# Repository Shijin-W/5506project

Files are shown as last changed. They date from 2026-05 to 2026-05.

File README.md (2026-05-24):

# Smart Multi-Cat Feeder

An IoT-based automatic cat feeder that identifies individual cats via RFID, serves food from dedicated bowls, measures food intake, and reports data to the cloud for remote monitoring.

## Table of Contents

- [Project Overview](#project-overview)
- [System Architecture](#system-architecture)
- [Hardware Setup](#hardware-setup)
- [Software Installation](#software-installation)
- [How It Works](#how-it-works)
- [Project Structure](#project-structure)
- [Code Overview](#code-overview)

## Project Overview

Multi-cat households face a common problem: one cat may eat another's food, leading to over-feeding or under-feeding. This project solves it by:

1. **RFID Identification** — Each cat wears an RFID tag on its collar. The feeder reads the tag and rotates a turntable to present the correct food bowl.
2. **Weight Measurement** — Load cells under each bowl measure food intake per session.
3. **Cloud Monitoring** — Feeding records are sent to Azure IoT Hub, processed by Azure Functions, and displayed on a web dashboard.
4. **Health Alerts** — If a cat hasn't eaten or exceeds its daily target, the system sends email alerts to the owner.

## Hardware Setup

### Components Required

| Component | Model | Qty | Interface |
|---|---|-----|---|
| Microcontroller | DFRobot FireBeetle 2 ESP32-E | 1 | — |
| RFID Reader | MFRC522 (I2C version) | 1 | I2C (0x2C) |
| Distance Sensor | VL53L1X Time-of-Flight | 1 | I2C (0x29) |
| Stepper Motor | 28BYJ-48 + ULN2003 driver | 1 | GPIO |
| Load Cell + Amplifier | HX711 | 2 | GPIO |
| RFID Tags | 13.56 MHz passive tags | 1 per cat | — |
| Power Supply | 5 V USB | 1 | — |

### Wiring Diagram

**I2C Bus** (shared by RFID reader and distance sensor):

| ESP32 Pin | Function |
|---|---|
| GPIO 21 | SDA |
| GPIO 22 | SCL |

**Stepper Motor** (28BYJ-48 via ULN2003 driver):

| ESP32 Pin | ULN2003 |
|---|---|
| GPIO 25 | IN1 |
| GPIO 26 | IN2 |
| GPIO 14 | IN3 |
| GPIO 13 | IN4 |

**Load Cells** (HX711 amplifiers):

| ESP32 Pin | Function |
|---|---|
| GPIO 17 | Left bowl HX711 DOUT  |
| GPIO 16 | Left bowl HX711 SCK |
| GPIO 18 | Right bowl HX711 DOUT |
| GPIO 19 | Right bowl HX711 SCK  |

### Physical Assembly

1. Mount the RFID reader at the bottom of the feeding tunnel, below the feeding window.
2. Mount the VL53L1X sensor on the tunnel side wall, facing the opposite wall.
3. Fix the stepper motor below the 3D-printed turntable (STL files in `hardware/3d/`).
4. Place two food bowls on the turntable, each sitting on a load cell.
5. Place the ESP32 and breadboard inside the housing box underneath the turntable.

## Software Installation

### Prerequisites

| Tool | Purpose |
|---|---|
| [PlatformIO](https://platformio.org/) | Build and upload ESP32 firmware |
| [Python 3.9+](https://www.python.org/) | Run the backend (Azure Functions) |
| [Azure CLI](https://learn.microsoft.com/en-us/cli/azure/) | Deploy backend to Azure (optional) |
| [Azure Functions Core Tools](https://learn.microsoft.com/en-us/azure/azure-functions/functions-run-local) | Run backend locally (optional) |

### 1. ESP32 Firmware

```bash
cd hardware/code
```

**Configure credentials** — edit `include/azure_config.h`:

```cpp
#define WIFI_SSID       "YourWiFiName"
#define WIFI_PASSWORD   "YourWiFiPassword"
#define IOT_HUB_HOST    "your-hub.azure-devices.net"
#define DEVICE_ID       "your-device-id"
#define DEVICE_KEY      "your-device-primary-key"
```

**Build and upload:**

```bash
pio run                          # Build firmware
pio run --target upload          # Flash to ESP32
pio device monitor --baud 115200 # View serial output
```

All library dependencies are listed in `platformio.ini` and will be downloaded automatically on the first build.

### 2. Azure Functions Backend

```bash
cd backend
pip install -r requirements.txt
```

**Configure environment** — copy the template and fill in your Azure credentials:

```bash
cp local.settings.template.json local.settings.json
# Edit local.settings.json with your Azure connection strings
```

Required settings: `AzureWebJobsStorage`, `STORAGE_CONNECTION_STRING`, `IOT_HUB_EVENTHUB_CONNECTION`, `IOT_HUB_EVENTHUB_NAME`, `IOT_HUB_CONNECTION_STRING`, `IOT_HUB_DEVICE_ID`, `LOCAL_TIMEZONE`.

**Seed initial cat profiles:**

```bash
python tools/seed_cat_profiles.py
```

**Deploy to Azure:**

```bash
func azure functionapp publish <function-app-name>
```

### 3. Web Dashboard (Frontend)

The frontend is a static website — no build step required.

```bash
cd frontend
python -m http.server 8088 --bind 127.0.0.1
```

Open `http://127.0.0.1:8088/index.html` in a browser.

To connect to a live backend, create `static/js/config.local.js`:

```javascript
window.FEEDER_CONFIG = {
  BACKEND_BASE_URL: "https://<function-app-name>.azurewebsites.net",
  FUNCTION_KEY: "<your-function-key>"
};
```

Load this file before `api.js` in the HTML pages.

## How It Works

### Firmware State Machine

The ESP32 firmware runs a **6-state finite state machine (FSM)** in a non-blocking `loop()`:

```
IDLE ──► DETECTING ──► OPENING ──► FEEDING ──► CLOSING ──► IDLE
                                                    
IDLE ──► SCAN_RFID ──► IDLE       (Cloud-triggered RFID binding)
```

| State | Description |
|---|---|
| **IDLE** | Distance sensor monitors the tunnel entrance. Transitions to DETECTING when an object is detected within 50 mm. |
| **DETECTING** | RFID reader attempts to identify the cat (5-second timeout). On match, motor begins rotating to the assigned bowl. |
| **OPENING** | Waits for the stepper motor to reach the target position. Records initial food weight from the load cell. |
| **FEEDING** | Cat is eating. Monitors for departure (3 seconds of continuous absence) and enforces a 5-minute max feeding time. |
| **CLOSING** | Motor returns to home position with backlash compensation. Feeding record (duration, intake) is uploaded to Azure IoT Hub. |
| **SCAN_RFID** | Triggered by a Cloud-to-Device command for remote RFID tag rebinding. Only available when IDLE. |

### Fault Tolerance

- **Sensor failure** — Any sensor that fails during boot is marked as unavailable. The system continues in degraded mode without freezing.
- **Network offline** — Feeding records are cached in a ring buffer (up to 10 records) and automatically resent when the connection is restored.
- **Token refresh** — SAS tokens are regenerated 2 minutes before expiry without interrupting the feeding process.

### Backend Processing

1. IoT Hub forwards device telemetry to Azure Functions via an Event Hub trigger.
2. The backend validates incoming events, maps RFID UIDs to cat profiles, and stores feeding records in Azure Table Storage.
3. Daily summaries and health alerts are computed automatically. If a cat hasn't eaten or exceeds its target, an alert is generated and optionally sent via email.
4. Pre-computed JSON files are written to Azure Blob Storage for fast frontend loading.

### Web Dashboard

| Page | Purpose |
|---|---|
| **Dashboard** (`index.html`) | Today's feeding count, total intake, active alerts, device status |
| **Feeding Records** (`records.html`) | Detailed feeding history with date filtering |
| **Analytics** (`analytics.html`) | Intake trends and charts over a date range |
| **Health Alerts** (`alerts.html`) | Alert history, manual resolution, email subscription |
| **Cat Management** (`cats.html`) | Edit cat profiles, set daily targets, rebind RFID tags |

## Project Structure

```
5506project/
├── hardware/
│   ├── code/
│   │   ├── include/
│   │   │   ├── config.h              # Pin assignments, thresholds, motor parameters
│   │   │   └── azure_config.h        # WiFi and Azure IoT Hub credentials
│   │   ├── src/
│   │   │   ├── main.cpp              # FSM logic and main loop
│   │   │   ├── rfid_module.cpp/h     # RFID reading, whitelist, NVS persistence
│   │   │   ├── motor_module.cpp/h    # Stepper motor with backlash compensation
│   │   │   ├── distance_module.cpp/h # VL53L1X cat presence detection
│   │   │   ├── loadcell_module.cpp/h # HX711 food weight measurement
│   │   │   └── azure_iot_module.cpp/h# MQTT, SAS auth, Device Twin, telemetry
│   │   └── platformio.ini            # Build config and library dependencies
│   ├── 3d/                           # 3D-printed enclosure STL files
│   └── images/                       # Hardware photos
│
├── backend/
│   ├── backend_app.py                # Azure Functions entry point (all HTTP + Event triggers)
│   ├── shared/
│   │   ├── status_service.py         # Core processing: feeding events, heartbeats, alerts
│   │   ├── table_repository.py       # Azure Table Storage data access layer
│   │   ├── blob_repository.py        # Azure Blob Storage data access layer
│   │   ├── twin_service.py           # Azure IoT Hub Device Twin and C2D messaging
│   │   ├── email_service.py          # Alert email notification (ACS / SMTP)
│   │   ├── alert_service.py          # Alert creation helpers
│   │   ├── config.py                 # App configuration from environment variables
│   │   ├── parser.py                 # IoT Hub message parser
│   │   ├── validator.py              # Feeding event payload validator
│   │   └── time_utils.py             # UTC/local time conversion utilities
│   ├── tests/                        # Unit tests (pytest)
│   └── tools/                        # Seed scripts, backfill, RFID update CLI
│
├── frontend/
│   ├── index.html                    # Dashboard page
│   ├── records.html                  # Feeding records page
│   ├── analytics.html                # Analytics page
│   ├── alerts.html                   # Health alerts page
│   ├── cats.html                     # Cat management page
│   └── static/
│       ├── css/style.css             # Global stylesheet
│       └── js/
│           ├── api.js                # Backend API client and data transformations
│           ├── dashboard.js          # Dashboard page logic
│           ├── records.js            # Records page logic
│           ├── analytics.js          # Analytics page logic (Chart.js)
│           ├── alerts.js             # Alerts page logic
│           └── cats.js               # Cat management page logic
│
└── README.md                         # This file
```

## Code Overview

### Hardware Modules

| Module | File(s) | Description |
|---|---|---|
| **Main FSM** | `main.cpp` | Implements the 6-state finite state machine. Calls sensor modules and Azure module each loop iteration. |
| **RFID** | `rfid_module.cpp/h` | Reads MFRC522 RFID tags over I2C. Manages a cat whitelist stored in ESP32 NVS (non-volatile storage). Supports mock tag injection for serial-based testing. |
| **Motor** | `motor_module.cpp/h` | Controls the 28BYJ-48 stepper motor via AccelStepper library. Implements a two-phase homing process: overshoot past home then return, to compensate for gear backlash. |
| **Distance** | `distance_module.cpp/h` | Reads VL53L1X Time-of-Flight sensor over I2C. Returns whether an object (cat) is within the threshold range. Runs in degraded mode if sensor init fails. |
| **Load Cell** | `loadcell_module.cpp/h` | Reads two HX711 load cell amplifiers. Averages 5 readings for stability. Note: negative readings after reboot are intentional — intake = initial − final weight. |
| **Azure IoT** | `azure_iot_module.cpp/h` | Manages WiFi, NTP, TLS, and MQTT connection to Azure IoT Hub. Generates SAS tokens using HMAC-SHA256. Handles Device Twin sync and Cloud-to-Device commands. Caches up to 10 unsent records for offline resilience. |

### Backend Functions

| Function | Trigger | Description |
|---|---|---|
| `process_iothub_feeding_event` | Event Hub | Processes raw IoT messages: validates, stores feeding events, recalculates daily summaries, and generates alerts. |
| `check_daily_feeding_status` | Timer (scheduled) | Ensures every cat has a daily status entry. Generates "not eaten" alerts for cats with no feedings. |
| `get_current_status` | HTTP GET | Returns current feeding status for all cats. |
| `get_daily_summary` | HTTP GET | Returns daily summary for a given date. |
| `get_recent_feedings` | HTTP GET | Returns feeding records for a given date. |
| `get_analytics_range` | HTTP GET | Returns aggregated analytics over a date range. |
| `get_alerts` / `get_alert_history` | HTTP GET | Returns alerts for a date or date range. |
| `resolve_alert` | HTTP POST | Manually resolves an open alert. |
| `alert_subscriptions` | HTTP GET/POST | Manage email alert subscriptions. |
| `update_cat_profile` | HTTP PATCH | Update cat name or daily target, pushes Device Twin. |
| `start_rfid_rebind_scan` | HTTP POST | Sends a Cloud-to-Device command to the ESP32 to scan a new RFID tag. |
| `sync_device_twin_config` | HTTP POST | Force-pushes the latest cat config to the Device Twin. |

### Frontend Pages

| Page | Key Features |
|---|---|
| **Dashboard** | Summary cards (feedings, intake, alerts, device status), today's intake by cat, latest feeding records, recent alerts. |
| **Feeding Records** | Full feeding history with date-range picker, per-record details (time, duration, intake). |
| **Analytics** | Chart.js line and bar charts for intake trends over custom date ranges. Per-cat summaries with averages. |
| **Health Alerts** | Alert history with severity levels, manual resolve action, email subscription management. |
| **Cat Management** | Edit cat names and daily targets, trigger RFID rebind scan workflow from the browser. |

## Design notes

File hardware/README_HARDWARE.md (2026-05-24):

# Smart Cat Feeder — Firmware (ESP32)

This directory contains the firmware for the Smart Cat Feeder, running on a DFRobot FireBeetle 2 ESP32-E. The system identifies cats via RFID, rotates a turntable to present the correct food bowl, measures food intake with load cells, and reports all data to Azure IoT Hub.

## Hardware Setup

### Components Required

| Component | Model | Quantity | Interface |
| --- | --- | --- | --- |
| Microcontroller | DFRobot FireBeetle 2 ESP32-E | 1 | — |
| RFID Reader | MFRC522 (Piico I2C version)  | 1 | I2C (addr 0x2C) |
| Distance Sensor | VL53L1X Time-of-Flight | 1 | I2C (addr 0x29) |
| Stepper Motor | 28BYJ-48 + ULN2003 driver | 1 | GPIO |
| Load Cell + Amplifier | HX711 | 2 | GPIO |
| RFID Tags | 13.56 MHz passive tags | per cat  | — |
| Power Supply | 5V USB | 1 | — |

### Wiring

**I2C Bus (shared by RFID and ToF):**

| ESP32 Pin | Function |
| --- | --- |
| GPIO 21 | SDA |
| GPIO 22 | SCL |

**Stepper Motor (28BYJ-48 via ULN2003):**

| ESP32 Pin | ULN2003 Pin |
| --- | --- |
| GPIO 25 | IN1 |
| GPIO 26 | IN2 |
| GPIO 14 | IN3 |
| GPIO 13 | IN4 |

**Load Cells (HX711):**

| ESP32 Pin | Function |
| --- | --- |
| GPIO 17 | Left bowl HX711 DOUT  |
| GPIO 16 | Left bowl HX711 SCK |
| GPIO 18 | Right bowl HX711 DOUT |
| GPIO 19 | Right bowl HX711 SCK  |

### Physical Assembly

1. Mount the RFID reader at the bottom of the feeding tunnel, just below the feeding window.
2. Mount the VL53L1X sensor on the side wall at the tunnel entrance, facing the opposite wall.
3. Fix the 28BYJ-48 motor below the 3D-printed turntable, with its shaft inserted into the centre.
4. Place two food bowls on the turntable, each on top of a load cell.
5. Place the ESP32 and breadboard inside the housing box underneath the turntable.

## Software Installation

### Prerequisites

- [PlatformIO](https://platformio.org/) (VS Code extension or CLI)
- USB cable for ESP32 flashing

### Configuration

1. Open `include/azure_config.h` and set your WiFi credentials and Azure IoT Hub device credentials:

```cpp
#define WIFI_SSID       "YourWiFiName"
#define WIFI_PASSWORD   "YourWiFiPassword"
#define IOT_HUB_HOST    "your-hub.azure-devices.net"
#define DEVICE_ID       "your-device-id"
#define DEVICE_KEY      "your-device-primary-key"
```

2. (Optional) Adjust sensor thresholds and motor parameters in `include/config.h` if your hardware setup differs from the default.

### Build and Upload

```bash
# Build the firmware
pio run

# Upload to the connected ESP32
pio run --target upload

# Open serial monitor to view logs
pio device monitor --baud 115200
```

All library dependencies (MFRC522_I2C, AccelStepper, HX711, VL53L1X, PubSubClient, ArduinoJson) are listed in `platformio.ini` and will be downloaded automatically on the first build.

## Project Structure

```
IOTProject/
├── include/
│   ├── config.h              # Pin assignments, thresholds, and motor parameters
│   └── azure_config.h        # WiFi and Azure IoT Hub credentials
├── src/
│   ├── main.cpp              # FSM logic and main loop
│   ├── rfid_module.cpp/h     # RFID reading, whitelist management, NVS persistence
│   ├── motor_module.cpp/h    # Stepper motor control with backlash compensation
│   ├── distance_module.cpp/h # VL53L1X distance sensor (cat presence detection)
│   ├── loadcell_module.cpp/h # HX711 load cell (food weight measurement)
│   └── azure_iot_module.cpp/h# Azure IoT Hub: MQTT, SAS auth, Device Twin, C2D, telemetry
└── platformio.ini            # Build configuration and library dependencies
```

## How It Works

The firmware runs a 6-state finite state machine (FSM) in a non-blocking main loop:

1. **IDLE** — Distance sensor monitors the tunnel entrance. When an object is detected, the system transitions to DETECTING.
2. **DETECTING** — RFID reader attempts to identify the cat. On success, the motor begins rotating to the assigned bowl position (OPENING). On timeout or cat departure, returns to IDLE.
3. **OPENING** — Waits for the stepper motor to reach the target bowl position. Records initial food weight from the load cell.
4. **FEEDING** — Cat is eating. The system monitors the distance sensor for cat departure (3-second absence confirmation) and enforces a 5-minute maximum feeding time.
5. **CLOSING** — Motor returns to home position with backlash compensation (overshoot + correction). Feeding record is uploaded to Azure IoT Hub.
6. **SCAN_RFID** — Triggered by a Cloud-to-Device command for remote RFID tag binding. Only available when IDLE.

### Fault Tolerance

- Any sensor failure at boot does not freeze the system; the module is marked as unavailable and the system runs in degraded mode.
- Feeding records are cached in a ring buffer (max 10) when the network is offline and automatically resent on reconnection.
- SAS tokens are auto-refreshed 2 minutes before expiry without interrupting the feeding process.

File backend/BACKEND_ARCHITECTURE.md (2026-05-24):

# Multicat Feeder Backend Architecture

本文档整理当前 `multicatfeeder` 项目的后端框架、Azure Functions 入口、数据存储设计、IoT 消息处理流程、告警逻辑、Device Twin 同步、邮件通知和前端数据接口。

## 1. Overall Architecture

后端是 Azure Functions Python 项目，使用经典 `function.json` 目录结构，而不是 Python v2 decorator 模式。

每个 Function 文件夹包含：

- `function.json`: Azure Functions binding 配置
- `__init__.py`: Function 入口，通常只转发到 `backend_app.py`

真实业务逻辑集中在：

- `backend_app.py`
- `shared/status_service.py`
- `shared/table_repository.py`
- `shared/blob_repository.py`
- `shared/parser.py`
- `shared/validator.py`
- `shared/alert_service.py`
- `shared/email_service.py`
- `shared/twin_service.py`
- `shared/time_utils.py`

当前后端使用：

- Azure Functions
- Azure IoT Hub Event Hub compatible endpoint
- Azure Table Storage
- Azure Blob Storage
- Azure IoT Hub Device Twin
- Azure IoT Hub Cloud-to-Device messages
- Azure Communication Email or SMTP, optional

## 2. Deployed Azure Resources

当前部署资源：

| Resource | Value |
|---|---|
| Resource group | `IOT-Group17` |
| Function App | `multicatfeeder-func-24417624` |
| IoT Hub | `multicatfeeder` |
| IoT Hub device | `feeder-esp32-01` |
| Project data storage account | `multicatproject` |
| Function runtime storage account | `mcfbackend24417624` |

项目数据和 Function runtime storage 是分开的。Table、Blob、前端静态站点数据主要在 `multicatproject`。

## 3. Runtime and Dependencies

`host.json` 使用 Azure Functions runtime v4 extension bundle:

```json
{
  "version": "2.0",
  "extensionBundle": {
    "id": "Microsoft.Azure.Functions.ExtensionBundle",
    "version": "[4.0.0, 5.0.0)"
  }
}
```

Python dependencies:

```txt
azure-functions==1.24.0
azure-data-tables
azure-storage-blob
azure-communication-email
tzdata
```

## 4. Configuration

配置类是 `AppConfig`，从环境变量读取。

Required settings:

| Setting | Purpose |
|---|---|
| `AzureWebJobsStorage` | Azure Functions runtime storage |
| `STORAGE_CONNECTION_STRING` | Project data storage connection string |
| `IOT_HUB_EVENTHUB_CONNECTION` | IoT Hub Event Hub compatible connection |
| `IOT_HUB_EVENTHUB_NAME` | IoT Hub Event Hub compatible name |
| `IOT_HUB_CONNECTION_STRING` | IoT Hub service connection string for twin/C2D |
| `IOT_HUB_NAME` | IoT Hub name |
| `IOT_HUB_DEVICE_ID` | Target feeder device id |
| `RAW_CONTAINER` | Raw IoT data container |

Business defaults:

| Setting | Default | Purpose |
|---|---:|---|
| `LOCAL_TIMEZONE` | `Australia/Perth` | Local date calculation |
| `DEFAULT_TARGET_DAILY_GRAMS` | `60` | Default cat daily target |
| `DEFAULT_MINIMUM_MEANINGFUL_INTAKE_GRAMS` | `2` | Very-low threshold |
| `DEFAULT_OVER_TARGET_RATIO` | `1.3` | Over-target threshold multiplier |
| `MIN_FEEDING_INTERVAL_HOURS` | `8` | Device feeding rule |
| `ALLOW_UNKNOWN_RFID` | `False` | Device feeding rule |

Email settings:

| Setting | Purpose |
|---|---|
| `ACS_CONNECTION_STRING` | Azure Communication Email connection |
| `ACS_SENDER_EMAIL` | ACS sender email |
| `SMTP_HOST` | SMTP server |
| `SMTP_PORT` | SMTP port |
| `SMTP_USERNAME` | SMTP username |
| `SMTP_PASSWORD` | SMTP password |
| `SMTP_FROM_EMAIL` | SMTP sender |
| `SMTP_USE_TLS` | SMTP TLS toggle |

## 5. Backend Layering

### 5.1 Trigger Layer

Function folders define Azure trigger bindings:

- HTTP trigger
- Timer trigger
- Event Hub trigger

The `__init__.py` files call functions in `backend_app.py`.

### 5.2 API / Orchestration Layer

`backend_app.py` handles:

- HTTP parameter parsing
- route parameter parsing
- JSON response formatting
- range validation
- calling repository/service functions
- alert insertion with notification
- Device Twin sync orchestration

### 5.3 Business Service Layer

`shared/status_service.py` handles:

- IoT message processing
- event validation and normalization
- feeding event persistence
- daily summary recalculation
- current status update
- alert generation and auto-resolution
- heartbeat health check handling
- RFID scan/rebind processing
- frontend output refresh

### 5.4 Repository Layer

`shared/table_repository.py` wraps Azure Table Storage.

`shared/blob_repository.py` wraps Azure Blob Storage.

Both modules also have in-memory variants for local unit tests.

### 5.5 Helper Layer

| Module | Responsibility |
|---|---|
| `parser.py` | Parse direct JSON or IoT Hub wrapper body |
| `validator.py` | Validate feeding event payload |
| `alert_service.py` | Build alerts and map severity |
| `email_service.py` | Email subscription and alert notification |
| `twin_service.py` | Device Twin, desired config, C2D messages |
| `time_utils.py` | UTC ISO, Unix timestamp, local date conversion |

## 6. Azure Functions

| Function | Trigger | Route / Schedule | Purpose |
|---|---|---|---|
| `process_iothub_feeding_event` | EventHub | IoT Hub Event Hub compatible endpoint | Process ESP32 telemetry |
| `check_daily_feeding_status` | Timer | `0 50 15 * * *` | Daily feeding status check |
| `health` | HTTP anonymous | `GET /api/health` | Health check |
| `get_current_status` | HTTP function key | `GET /api/current-status` | Current cat status |
| `get_daily_summary` | HTTP function key | `GET /api/daily-summary?date=YYYY-MM-DD` | Daily summary by date |
| `get_recent_feedings` | HTTP function key | `GET /api/recent-feedings?date=YYYY-MM-DD` | Feeding records by date |
| `get_analytics_range` | HTTP function key | `GET /api/analytics/range?startDate=&endDate=` | Range analytics |
| `get_alerts` | HTTP function key | `GET /api/alerts?date=YYYY-MM-DD` | Alerts by date |
| `get_alert_history` | HTTP function key | `GET /api/alerts/history?startDate=&endDate=` | Alert history range |
| `resolve_alert` | HTTP function key | `POST /api/alerts/{alertId}/resolve?date=` | Resolve alert |
| `get_frontend_data` | HTTP function key | `GET /api/frontend-data?partition=` | Frontend cache data |
| `alert_subscriptions` | HTTP function key | `GET/POST /api/alert-subscriptions` | Email subscriptions |
| `get_device_config_status` | HTTP function key | `GET /api/device-config-status` | Device Twin sync status |
| `admin_update_cat_rfid` | HTTP function key | `POST /api/cats/{catId}/rfid` | Update cat RFID |
| `admin_update_cat_profile` | HTTP function key | `POST/PATCH /api/cats/{catId}/profile` | Update cat profile |
| `admin_start_rfid_rebind_scan` | HTTP function key | `POST /api/cats/{catId}/rfid/rebind-scan` | Start RFID scan via C2D |
| `admin_sync_device_twin_config` | HTTP function key | `POST /api/device-twin/sync` | Manually sync desired config |

## 7. Azure Table Storage Model

The backend uses these tables:

| Table | Purpose |
|---|---|
| `CatProfiles` | Active cat profile master data |
| `RfidMap` | Active RFID UID to cat mapping |
| `RfidHistory` | RFID mapping history |
| `FeedingEvents` | Normalized feeding events |
| `DailySummary` | Per-cat daily totals/status |
| `CurrentStatus` | Current dashboard status per cat |
| `Alerts` | Open/resolved alerts |
| `FrontendData` | Precomputed frontend cache rows |
| `RfidOperations` | RFID rebind operation state |
| `EmailSubscriptions` | Email alert subscribers |
| `AlertEmailNotifications` | Alert email delivery state |

Initial cats:

| catId | catName | currentCatUID | targetDailyGrams |
|---|---|---|---:|
| `cat_a` | `CatA` | `B9BD18C9` | `60` |
| `cat_b` | `CatB` | `0420D6BAFD1691` | `60` |

## 8. Blob Storage Outputs

Blob containers:

| Container | Purpose |
|---|---|
| `parsed-events` | Normalized event archive |
| `feeding-events` | Feeding event archive |
| `backend-data` | JSON outputs for frontend/debugging |
| `error-events` | Invalid payloads and sensor/RFID errors |

Path patterns:

```txt
parsed-events/year=YYYY/month=MM/day=DD/catId={catId}/{eventId}.json
feeding-events/year=YYYY/month=MM/day=DD/catId={catId}/{eventId}.json
error-events/year=YYYY/month=MM/day=DD/{errorId}.json
```

`backend-data` outputs:

```txt
current-status.json
daily-summary/{localDate}.json
recent-feedings/{localDate}.json
alerts/latest.json
```

## 9. IoT Message Processing

Entry point:

```txt
process_iothub_feeding_event(events)
```

Main flow:

1. Event Hub trigger receives one or more IoT Hub events.
2. Each event body is passed to `StatusService.process_raw_message`.
3. `parse_iothub_message` parses either direct JSON or IoT Hub wrapper JSON.
4. The payload is routed by `payload["event"]`.
5. Supported events:
   - `feeding_complete`
   - `heartbeat`
   - `scan_status`
   - `tag_scanned`
6. Unsupported events are ignored.
7. Valid feeding events are normalized, persisted, summarized, and published to frontend outputs.
8. Invalid events generate error blobs and alerts.

Supported message formats:

Direct JSON:

```json
{
  "deviceId": "FEEDER-01",
  "event": "feeding_complete"
}
```

IoT Hub wrapper:

```json
{
  "Body": "base64-encoded-json",
  "SystemProperties": {
    "connectionDeviceId": "feeder-esp32-01"
  }
}
```

Extracted metadata:

- `ingestedAtUtc`
- `iotHubEnqueuedTimeUtc`
- `connectionDeviceId`

## 10. Feeding Event Validation

Required fields:

```txt
deviceId
catName
catUID
event
feedingStartTime
feedingEndTime
durationSec
intakeGrams
```

Validation rules:

- `event` must be `feeding_complete`.
- `feedingStartTime` and `feedingEndTime` must be Unix timestamps.
- timestamps must be after `2020-01-01T00:00:00Z`.
- start time must be earlier than or equal to end time.
- `durationSec` must be numeric.
- if `durationSec != feedingEndTime - feedingStartTime`, a warning is recorded but the event is still accepted.
- `intakeGrams` must be numeric.
- `intakeGrams` must be greater than or equal to `0`.

Special case:

- If `event == feeding_complete` but `intakeGrams is null`, the backend treats it as a scale sensor error instead of a valid feeding event.

## 11. Feeding Event Normalization

Normalized event keys:

```txt
PartitionKey = {catId}_{localDate}
RowKey = {deviceId}-{catId}-{feedingEndTimestamp}
```

Normalized fields:

```txt
eventId
deviceId
catId
catName
catUID
eventType = feeding_complete
feedingStartTimestamp
feedingEndTimestamp
feedingStartTimeUtc
feedingEndTimeUtc
localDate
durationSec
intakeGrams
isValid
validationErrors
iotHubEnqueuedTimeUtc
connectionDeviceId
ingestedAtUtc
createdAtUtc
```

`localDate` is calculated from `feedingEndTimeUtc` using `LOCAL_TIMEZONE`, currently `Australia/Perth`.

Deduplication:

- `FeedingEvents` uses `PartitionKey + RowKey`.
- Duplicate inserts return `duplicate`.
- Duplicate events do not recalculate daily totals again.

## 12. Daily Summary

Daily summary is recalculated after a new feeding event is inserted:

```txt
recalculate_daily_summary(catId, localDate)
```

The service:

1. Loads cat profile.
2. Loads all feeding events for that cat/date.
3. Sorts events by `feedingEndTimestamp`.
4. Calculates total intake.
5. Calculates feeding count.
6. Sets first/last feeding timestamps.
7. Calculates `todayStatus`.
8. Upserts `DailySummary`.
9. Upserts `CurrentStatus`.
10. Resolves old feeding alerts if status is normal.
11. Inserts a new status alert if needed.

Daily summary fields:

```txt
PartitionKey = catId
RowKey = localDate

catId
catName
date
totalIntakeGrams
feedingCount
firstFeedingCompletedTimeUtc
lastFeedingCompletedTimeUtc
targetDailyGrams
minimumMeaningfulIntakeGrams
overTargetRatio
todayStatus
updatedAtUtc
```

Status calculation:

```txt
total == 0                         -> not_eaten
total < minimum                    -> very_low_intake
total < target                     -> under_target
total <= target * overTargetRatio  -> normal
otherwise                          -> over_target
```

## 13. Current Status

`CurrentStatus` stores one row per active cat.

Keys:

```txt
PartitionKey = CURRENT
RowKey = catId
```

Fields:

```txt
catId
catName
currentCatUID
lastFeedingCompletedTimeUtc
lastIntakeGrams
todayIntakeGrams
targetDailyGrams
todayStatus
updatedAtUtc
```

This table is a primary data source for Dashboard and Cat Management.

## 14. Daily Timer

Function:

```txt
check_daily_feeding_status
```

Schedule:

```txt
0 50 15 * * *
```

This runs at 15:50 UTC, which is 23:50 in Perth.

Purpose:

1. Determine current Perth local date.
2. Iterate all active cats.
3. Create a 0g daily summary if no summary exists.
4. Update `CurrentStatus`.
5. Generate feeding-status alerts, such as `not_eaten`.
6. Refresh backend Blob outputs and `FrontendData`.

## 15. Alert System

Alerts are stored in the `Alerts` table.

Keys:

```txt
PartitionKey = localDate
RowKey = alertId
```

Alert fields:

```txt
alertId
catId
catName
alertType
severity
message
createdAtUtc
status
resolvedAtUtc
resolvedBy
updatedAtUtc
```

Alert id format:

```txt
alert-{catId or system}-{date}-{suffix}
```

Supported alert types:

| alertType | severity |
|---|---|
| `invalid_payload` | `high` |
| `unknown_rfid` | `high` |
| `not_eaten` | `high` |
| `very_low_intake` | `medium` |
| `under_target` | `low` |
| `over_target` | `medium` |
| `device_config_out_of_sync` | `medium` |
| `device_health_error` | `high` |
| `processing_error` | `high` |
| `scale_sensor_error` | `high` |

Feeding status alert messages:

- `not_eaten`: no completed feeding recorded.
- `very_low_intake`: total intake below minimum meaningful threshold.
- `under_target`: total intake below daily target.
- `over_target`: total intake above configured over-target threshold.

Auto-resolution:

- If a cat's daily status becomes `normal`, open feeding alerts for that cat/date are resolved.
- Resolved alert types:
  - `not_eaten`
  - `very_low_intake`
  - `under_target`
  - `over_target`
- `resolvedBy = auto_feeding_normal`

Manual resolution:

```txt
POST /api/alerts/{alertId}/resolve?date=YYYY-MM-DD
```

Manual resolution sets:

```txt
status = resolved
resolvedAtUtc = now
resolvedBy = manual
updatedAtUtc = now
```

## 16. Heartbeat Handling

If payload event is `heartbeat`, the backend reads:

```txt
timestamp
deviceId
rfid_ok
tof_ok
motor_ok
scale_ok
load_cell_ok
```

Failed checks generate `device_health_error` alerts.

Recovered checks can auto-resolve matching same-day device health alerts.

Health check labels:

| Payload key | Alert label |
|---|---|
| `rfid_ok` | `rfid` |
| `tof_ok` | `tof` |
| `motor_ok` | `motor` |
| `scale_ok` | `scale` |
| `load_cell_ok` | `load_cell` |

## 17. Error Handling

### 17.1 Invalid Payload

Invalid payload flow:

1. Create `invalid_payload` error id based on payload hash.
2. Write error blob.
3. Insert `invalid_payload` alert.
4. Return processing result `invalid_payload`.

### 17.2 Unknown RFID

Unknown RFID flow:

1. Extract `catUID`.
2. Write error blob.
3. Insert `unknown_rfid` alert.
4. Do not write feeding event.

### 17.3 Scale Sensor Error

Scale sensor error flow:

1. Triggered when `feeding_complete` has `intakeGrams = null`.
2. Resolve local date from feeding end time when possible.
3. Try to identify cat by RFID.
4. Write error blob.
5. Insert `scale_sensor_error` alert.
6. Do not write feeding event.

### 17.4 Processing Exception

Unhandled processing exceptions in EventHub trigger:

1. Are logged.
2. Generate `processing_error` alert.

## 18. FrontendData Cache

`update_backend_outputs(localDate)` writes both Blob JSON and `FrontendData` table partitions.

FrontendData partitions:

```txt
current-status
daily-summary_{localDate}
recent-feedings_{localDate}
alerts_latest
```

Generic row structure:

```txt
PartitionKey
RowKey
dataType
date
payloadJson
updatedAtUtc
```

The backend also flattens simple payload fields into the row for direct frontend use.

Important note:

`alerts_latest` is generated when a specific local date is refreshed. It may not represent the actual global latest alert history. Dashboard should use `/api/alerts/history` for recent alerts.

## 19. Analytics Range API

Endpoint:

```txt
GET /api/analytics/range?startDate=YYYY-MM-DD&endDate=YYYY-MM-DD
```

Validation:

- `startDate` is required.
- `endDate` is required.
- `startDate <= endDate`.
- Date range cannot exceed 366 days.

Response:

```txt
startDate
endDate
catSummaries
dailySeries
feedingRecords
totals
```

`catSummaries`:

```txt
catId
catName
totalIntakeGrams
feedingCount
averageIntakeGrams
targetDailyGrams
daysWithData
```

`dailySeries`:

```txt
date
catId
catName
totalIntakeGrams
feedingCount
```

`feedingRecords`:

```txt
eventId
catId
catName
catUID
feedingStartTimeUtc
feedingEndTimeUtc
durationSec
intakeGrams
localDate
```

`totals`:

```txt
totalIntakeGrams
feedingCount
averageIntakeGrams
```

## 20. Alert History API

Endpoint:

```txt
GET /api/alerts/history?startDate=YYYY-MM-DD&endDate=YYYY-MM-DD
```

Validation:

- `startDate` is required.
- `endDate` is required.
- `startDate <= endDate`.
- Date range cannot exceed 366 days.

Logic:

1. Iterate each date in the range.
2. Query `Alerts` by `PartitionKey = date`.
3. Strip Azure Table internal fields.
4. Ensure `date` is present.
5. Sort by `createdAtUtc` and `alertId` descending.
6. Count open and resolved alerts.

Response:

```txt
startDate
endDate
alerts
totals.alertCount
totals.openCount
totals.resolvedCount
```

## 21. Device Twin

`TwinService` uses IoT Hub REST API with SAS token.

Supported operations:

- `update_device_twin`
- `get_device_twin`
- `send_c2d_message`
- `compare_desired_reported_config_version`

Desired properties are built from active cat profiles:

```json
{
  "configVersion": 1,
  "cats": {
    "cat_a": {
      "catName": "CatA",
      "catUID": "B9BD18C9",
      "targetDailyGrams": 60,
      "minimumMeaningfulIntakeGrams": 2
    }
  },
  "feedingRules": {
    "minFeedingIntervalHours": 8,
    "allowUnknownRfid": false
  }
}
```

`configVersion` is the max `configVersion` among active cat profiles.

`GET /api/device-config-status`:

1. Reads Device Twin.
2. Compares desired `configVersion` with reported `configVersionApplied`.
3. Returns online state, connection state, last activity time, known cats and config sync state.
4. If not in sync, inserts a `device_config_out_of_sync` alert.

Returned fields include:

```txt
deviceId
online
connectionState
lastActivityTimeUtc
deviceStatus
onlineCheckedAtUtc
desiredConfigVersion
reportedConfigVersionApplied
inSync
lastSyncTime
knownCats
```

## 22. Cat Profile Update

Endpoint:

```txt
PATCH /api/cats/{catId}/profile
POST /api/cats/{catId}/profile
```

Body:

```json
{
  "catName": "New Name",
  "targetDailyGrams": 70
}
```

Rules:

- At least `catName` or `targetDailyGrams` is required.
- `catName` cannot be empty.
- `targetDailyGrams` must be greater than 0.

Update flow:

1. Load cat profile.
2. Update `catName` and/or `targetDailyGrams`.
3. Increment `configVersion`.
4. Upsert `CatProfiles`.
5. Update `CurrentStatus`.
6. Update active `RfidMap`.
7. Update active `RfidHistory`.
8. If today's `DailySummary` exists, update its cat name and target.
9. Refresh backend outputs for today's local date.
10. Rebuild Device Twin desired properties.
11. Patch Device Twin.

Response:

```txt
catId
catName
currentCatUID
targetDailyGrams
configVersion
deviceTwinUpdateStatus
```

## 23. RFID Update

Endpoint:

```txt
POST /api/cats/{catId}/rfid
```

Body:

```json
{
  "newCatUID": "A1B2C3D4",
  "effectiveTimeUtc": "2026-05-18T10:00:00Z"
}
```

Flow:

1. Validate cat exists.
2. Validate new UID is not active for another cat.
3. Mark old `RfidMap` inactive.
4. Mark old active `RfidHistory` rows inactive.
5. Insert new active `RfidMap`.
6. Insert new active `RfidHistory`.
7. Update `CatProfiles.currentCatUID`.
8. Increment `configVersion`.
9. Update `CurrentStatus.currentCatUID`.
10. Rebuild and patch Device Twin desired config.

Response:

```txt
catId
oldCatUID
newCatUID
configVersion
deviceTwinUpdateStatus
```

## 24. RFID Rebind Scan

Endpoint:

```txt
POST /api/cats/{catId}/rfid/rebind-scan
```

Body:

```json
{
  "timeoutSec": 120,
  "operationId": "optional"
}
```

Tray mapping:

| catId | trayIndex |
|---|---:|
| `cat_a` | `0` |
| `cat_b` | `1` |

Flow:

1. Validate cat exists.
2. Validate tray mapping exists.
3. Create RFID operation in `RfidOperations`.
4. Build C2D command.
5. Send command to device.
6. Update operation status to `command_sent` or `failed`.

C2D command:

```json
{
  "action": "start_scan",
  "operationId": "...",
  "trayIndex": 0,
  "timeoutSec": 120
}
```

Operation fields:

```txt
PartitionKey = RFID_REBIND
RowKey = operationId

operationId
operationType = rebind_rfid
status
targetCatId
targetCatName
oldCatUID
trayIndex
timeoutSec
createdAtUtc
updatedAtUtc
expiresAtUtc
commandJson
commandSentAtUtc
failureReason
```

Supported device follow-up events:

- `scan_status`
- `tag_scanned`

`scan_status` mappings:

| Device status | Operation status |
|---|---|
| `armed` | `armed` |
| `scanned` | `scan_received` |
| `timeout` | `expired` |
| `cancelled` | `cancelled` |
| `failed` | `failed` |

`tag_scanned` flow:

1. Validate `operationId` and `uid`.
2. Load RFID operation.
3. Reject expired operation.
4. Reject non-active operation status.
5. Reject UID already active for another cat.
6. Apply `update_rfid_mapping`.
7. Patch Device Twin desired config.
8. Mark operation as `applied`.
9. Refresh backend outputs.

## 25. Email Notification

Endpoint:

```txt
GET /api/alert-subscriptions
GET /api/alert-subscriptions?email=user@example.com
POST /api/alert-subscriptions
```

POST body:

```json
{
  "email": "user@example.com",
  "action": "subscribe"
}
```

Supported actions:

```txt
subscribe
unsubscribe
toggle
active
inactive
```

Subscription row:

```txt
PartitionKey = EMAIL_SUBS
RowKey = sha256(normalizedEmail)

email
emailHash
status
minSeverity
createdAtUtc
updatedAtUtc
```

Notification rules:

- Only alerts with severity >= `medium` are sent.
- Each subscriber can have its own `minSeverity`.
- Low alerts are not sent by default.
- `AlertEmailNotifications` prevents duplicate sends.
- New active subscribers receive recent open medium/high backlog alerts, max 4.

Delivery providers:

1. Azure Communication Email, if `ACS_CONNECTION_STRING` and `ACS_SENDER_EMAIL` are configured.
2. SMTP, if SMTP settings are configured.
3. Otherwise notification status becomes `email_not_configured`.

Notification row:

```txt
PartitionKey = alertId
RowKey = emailHash

alertId
emailHash
email
severity
status
createdAtUtc
updatedAtUtc
sentAtUtc
error
```

## 26. Frontend-Facing API Summary

Main frontend APIs:

```txt
GET /api/frontend-data?partition=current-status
GET /api/frontend-data?partition=daily-summary_YYYY-MM-DD
GET /api/frontend-data?partition=recent-feedings_YYYY-MM-DD
GET /api/analytics/range?startDate=YYYY-MM-DD&endDate=YYYY-MM-DD
GET /api/alerts/history?startDate=YYYY-MM-DD&endDate=YYYY-MM-DD
GET /api/device-config-status
PATCH /api/cats/{catId}/profile
POST /api/alerts/{alertId}/resolve?date=YYYY-MM-DD
GET /api/alert-subscriptions
POST /api/alert-subscriptions
```

Current frontend usage:

- Dashboard uses current status, analytics range, alert history and device config status.
- Feeding Records uses analytics range.
- Alert page uses alert history and resolve alert.
- Cat Management uses current status and cat profile update.
- Email subscription UI uses alert subscription APIs.

## 27. Testing

Tests are in `tests/`.

Covered areas:

- parser
- validator
- status service
- analytics range
- alert history
- RFID update
- Device Twin service
- email notification

The tests use in-memory repositories where possible, avoiding live Azure dependencies.

## 28. Deployment

Deploy command:

```powershell
func azure functionapp publish multicatfeeder-func-24417624 --python
```

When adding a new HTTP Function, ensure its function-specific key is configured to match the frontend key, otherwise the frontend receives `401`.

Known functions that were added later and need valid function keys:

- `get_alert_history`
- `admin_update_cat_profile`

## 29. Important Implementation Notes

- Runtime entry module is `backend_app.py`.
- The project intentionally uses classic `function.json` folders because a root `function_app.py` can cause Azure's Python v2 worker indexing path to take over.
- `localDate` is based on backend timezone conversion, not browser time.
- Feeding event deduplication is based on `{deviceId}-{catId}-{feedingEndTimestamp}`.
- `alerts_latest` is not a reliable global history source; use `alerts/history` for recent or historical alert displays.
- Cat name updates propagate to `CatProfiles`, `CurrentStatus`, active RFID mapping/history, today's summary, frontend outputs and Device Twin desired config.
- Device Twin sync status can itself generate `device_config_out_of_sync` alerts.
- Email alert sending is best-effort; delivery failure is recorded in `AlertEmailNotifications`.

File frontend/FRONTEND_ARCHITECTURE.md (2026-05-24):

# Multicat Feeder Frontend Architecture

本文档整理当前 `multicatfeeder` 项目的前端架构、页面结构、共享数据层、后端 API 调用、各页面数据流、实时刷新策略、部署方式和已知实现细节。

## 1. Overall Architecture

前端是一个纯静态 Web 应用，没有构建系统，也没有前端框架编译流程。

技术栈：

- HTML
- CSS
- Vanilla JavaScript
- jQuery
- Bootstrap 5
- Bootstrap Icons
- Chart.js
- Google Font: Inter

前端直接部署为静态文件，可以通过：

- 本地 `python -m http.server`
- Azure Storage Static Website

运行。

当前静态站点部署地址：

```txt
https://multicatproject.z8.web.core.windows.net/
```

本地启动方式：

```txt
5506-iot-smart-cat-feeder-frontend/OPEN_FRONTEND.bat
```

该 bat 会：

1. 切换到前端目录。
2. 杀掉已有的 `127.0.0.1:8088` 监听进程。
3. 启动 `python -m http.server 8088 --bind 127.0.0.1`。
4. 打开 `http://127.0.0.1:8088/index.html?v=20260518-local-refresh`。

## 2. Frontend File Structure

```txt
5506-iot-smart-cat-feeder-frontend/
  index.html
  records.html
  analytics.html
  alerts.html
  cats.html
  OPEN_FRONTEND.bat
  static/
    css/
      style.css
    js/
      api.js
      dashboard.js
      records.js
      analytics.js
      alerts.js
      cats.js
      mockData.js
```

Page mapping:

| Page | JS | Purpose |
|---|---|---|
| `index.html` | `dashboard.js` | Dashboard overview |
| `records.html` | `records.js` | Feeding record history |
| `analytics.html` | `analytics.js` | Intake analytics and charts |
| `alerts.html` | `alerts.js` | Alert details, history, email subscription |
| `cats.html` | `cats.js` | Cat profile management and RFID rebind |

Shared files:

| File | Purpose |
|---|---|
| `static/js/api.js` | Shared global state, backend API wrappers, data transformers, formatting helpers |
| `static/css/style.css` | Shared visual styles |
| `static/js/mockData.js` | Legacy/mock data support |

## 3. Page Loading Model

Each HTML page loads:

1. Google Fonts
2. Bootstrap CSS
3. Bootstrap Icons
4. `static/css/style.css`
5. jQuery
6. Bootstrap JS
7. `static/js/api.js`
8. Page-specific JS

Example from Dashboard:

```html
<script src="static/js/api.js?v=20260518-dashboard-recent-alerts"></script>
<script src="static/js/dashboard.js?v=20260518-dashboard-recent-alerts"></script>
```

The query string version is used for cache busting.

There is no module loader. All JavaScript files share global variables and functions.

## 4. Shared Global State

`api.js` defines shared global state:

```js
var cats = [];
var feedingRecords = [];
var healthAlerts = [];

var deviceStatus = {
  feederOnline: false,
  lastSyncTime: "Not synced",
  lastSyncTimeUtc: "",
  connectionState: "Unknown",
  lastSyncLabel: "Last sync"
};

var currentDataDate = "";
```

These arrays are overwritten or reused by page-specific scripts.

Important implications:

- Each page has its own browser page lifecycle.
- State is not persisted between pages.
- Each page reloads data on `$(document).ready`.
- Page scripts depend on `api.js` being loaded first.

## 5. Backend Configuration

Backend base URL is defined in `api.js`:

```js
const BACKEND_BASE_URL = "https://multicatfeeder-func-24417624.azurewebsites.net";
```

Function key is also stored in `api.js`:

```js
const FUNCTION_KEY = "...";
```

Every protected Azure Function request includes:

```txt
code={FUNCTION_KEY}
```

All API calls also include:

```txt
_={Date.now()}
```

This is used to avoid browser/proxy caching.

Fetch calls use:

```js
{ cache: "no-store" }
```

## 6. Shared API Wrapper Functions

Defined in `api.js`.

### 6.1 FrontendData Cache

```js
fetchFrontendData(partition)
```

Calls:

```txt
GET /api/frontend-data?partition={partition}
```

Used partitions:

```txt
current-status
daily-summary_YYYY-MM-DD
recent-feedings_YYYY-MM-DD
alerts_latest
```

### 6.2 Device Status

```js
fetchDeviceConfigStatus()
```

Calls:

```txt
GET /api/device-config-status
```

Used to display:

- online/offline
- last activity
- Device Twin sync status

### 6.3 Analytics Range

```js
fetchAnalyticsRange(startDate, endDate)
```

Calls:

```txt
GET /api/analytics/range?startDate=YYYY-MM-DD&endDate=YYYY-MM-DD
```

Used by:

- Dashboard today stats
- Dashboard latest feeding records
- Feeding Records page
- Analytics page

### 6.4 Alert History

```js
fetchAlertHistory(startDate, endDate)
```

Calls:

```txt
GET /api/alerts/history?startDate=YYYY-MM-DD&endDate=YYYY-MM-DD
```

Used by:

- Dashboard Recent Health Alerts
- Health Alerts page

### 6.5 Alert Subscription

```js
fetchAlertSubscriptions()
fetchAlertSubscriptionStatus(email)
toggleAlertEmailSubscription(email)
```

Calls:

```txt
GET /api/alert-subscriptions
GET /api/alert-subscriptions?email={email}
POST /api/alert-subscriptions
```

Used by:

- Health Alerts page email notification card

### 6.6 Resolve Alert

```js
resolveBackendAlert(alertId, date)
```

Calls:

```txt
POST /api/alerts/{alertId}/resolve?date=YYYY-MM-DD
```

Used by:

- Alert Details `Mark as Resolved` button

### 6.7 RFID Rebind

```js
startRfidRebindScan(backendCatId, timeoutSec)
```

Calls:

```txt
POST /api/cats/{catId}/rfid/rebind-scan
```

Used by:

- Cat Management `Rebind RFID`

### 6.8 Cat Profile Update

```js
updateCatProfile(backendCatId, profile)
```

Calls:

```txt
PATCH /api/cats/{catId}/profile
```

Used by:

- Cat Management edit form

## 7. Shared Data Loading

Main shared loader:

```js
loadBackendData(selectedDate)
```

Flow:

1. Load `current-status` from `/api/frontend-data`.
2. Determine `dateToLoad`:
   - `selectedDate`, if provided
   - latest feeding date from current status
   - Perth today fallback
3. Transform current status into `cats`.
4. Load device config status from `/api/device-config-status`.
5. Transform device status into `deviceStatus`.
6. Load `recent-feedings_{dateToLoad}`.
7. Transform into `feedingRecords`.
8. Load `alerts_latest`.
9. Transform into `healthAlerts`.
10. Update the device sync pill and footer.

If loading fails:

1. Logs error.
2. Calls `loadFallbackData()`.
3. Updates sync pill/footer with fallback status.
4. Returns `false`.

Important note:

`loadBackendData` still loads `alerts_latest` as a general fallback. Dashboard and Alerts page override alert data with `/api/alerts/history` where accurate history is required.

## 8. Data Transformers

### 8.1 Cats

```js
transformCats(rows)
```

Converts backend current status rows into frontend cat objects:

```txt
id
backendCatId
name
rfidTag
assignedBowl
dailyTarget
todayIntakeGrams
lastIntakeGrams
todayStatus
lastFeedingCompletedTimeUtc
```

The frontend currently displays up to 2 cats:

```js
rows.slice(0, 2)
```

### 8.2 Feeding Records

```js
transformFeedingRecords(rows, catsList)
```

Converts backend records into frontend records:

```txt
id
catId
backendCatId
catName
rfidTag
startTime
endTime
startTimeUtc
endTimeUtc
localDate
durationSec
intakeGrams
```

Cat name handling:

- If a record's `catId` matches a current cat profile, current cat name is used.
- Otherwise historical `row.catName` is used.

This ensures Cat Management name changes appear across other pages.

### 8.3 Alerts

```js
transformAlerts(rows)
```

Converts backend alerts into frontend alert objects:

```txt
id
catId
catName
level
message
createdAt
createdAtUtc
updatedAtUtc
resolvedAtUtc
alertDate
status
alertType
```

Status mapping:

```txt
open / active / unresolved -> Unresolved
otherwise                  -> Resolved
```

Level mapping:

```txt
high / critical / very_low / not_eaten -> High
medium / warning / unknown_rfid / over_target -> Medium
otherwise -> Low
```

Cat name handling:

- If alert `catId` matches a current cat profile, current cat name is used.
- Otherwise backend alert `catName` is used.

### 8.4 Device Status

```js
transformDeviceStatus(rows, backendStatus)
```

Primary path:

- Uses `/api/device-config-status`.
- `backendStatus.online` drives online/offline.
- `lastActivityTimeUtc`, `lastSyncTime`, or `onlineCheckedAtUtc` drives displayed time.

Fallback path:

- Uses `current-status.updatedAtUtc`.
- Considers the device online if the latest update is within `DEVICE_ONLINE_THRESHOLD_MINUTES`, currently 10 minutes.

## 9. Time and Formatting

Timezone:

```txt
Australia/Perth
```

Helpers:

```js
getPerthToday()
getPerthDateFromUtc(utcTimeString)
formatPerthDateFromDate(date)
formatPerthDate(isoString)
formatPerthDateTime(isoString)
roundOneDecimal(value)
```

Dates are formatted as:

```txt
YYYY-MM-DD
YYYY-MM-DD HH:mm
```

Dashboard uses backend/device clock where possible to avoid browser-local date mismatch.

## 10. Device Sync Display

```js
updateDeviceSyncDisplay()
```

Updates all:

```txt
.device-sync-pill
.app-footer
```

Displayed content:

```txt
Last activity: YYYY-MM-DD HH:mm | Device ID: FEEDER-01
```

or fallback:

```txt
Last sync: ...
```

The sync dot uses:

```txt
online
offline
```

classes.

## 11. Dashboard Page

Files:

- `index.html`
- `static/js/dashboard.js`

Dashboard sections:

- Today's Feedings
- Total Intake Today
- Active Alerts
- Device Status
- Today's Intake by Cat
- Latest Feeding Records
- Recent Health Alerts

### 11.1 Polling

Dashboard polls backend every 15 seconds:

```js
const DASHBOARD_POLL_INTERVAL_MS = 15000;
```

Flow:

```js
$(document).ready(async function () {
  await refreshDashboardData({ preserveExistingOnFailure: false });
  startDashboardPolling();
});
```

Polling safeguards:

- Prevents overlapping refreshes with `dashboardRefreshInProgress`.
- Skips refresh while tab is hidden when `skipWhenHidden` is true.
- Refreshes immediately when tab becomes visible again.
- Stops timer on `beforeunload`.
- Can preserve previous state if refresh fails.

### 11.2 Dashboard Today Calculation

```js
getDashboardToday()
```

Attempts to derive today from backend/device data:

1. `backendStatus.onlineCheckedAtUtc`
2. `backendStatus.lastActivityTimeUtc`
3. browser Perth date fallback

This prevents selected data from being tied to stale browser or local assumptions.

### 11.3 Dashboard Data Flow

```js
loadDashboardTodayData(options)
```

Flow:

1. Snapshot current dashboard state.
2. Determine backend/device today.
3. Load current backend data for today.
4. Filter feeding records to today.
5. Calculate cat totals from records.
6. Fetch `/api/analytics/range` for today.
7. Override cat daily totals with backend analytics summary.
8. Set today's `feedingRecords`.
9. Load latest feeding records from recent 30 days.
10. Load recent unresolved alerts from recent 7 days.
11. Set `currentDataDate`.

### 11.4 Latest Feeding Records

Constants:

```js
const DASHBOARD_LATEST_RECORD_DAYS = 30;
```

Logic:

- Fetch analytics range from `today - 29 days` to `today`.
- Transform all returned feeding records.
- Sort by feeding time.
- Render latest 5 records.

This list is not limited to today and is not affected by any selected date on other pages.

### 11.5 Recent Health Alerts

Constants:

```js
const DASHBOARD_RECENT_ALERT_DAYS = 7;
const DASHBOARD_RECENT_ALERT_LIMIT = 3;
```

Logic:

- Fetch `/api/alerts/history` from `today - 6 days` to `today`.
- Transform alerts.
- Keep only `Unresolved`.
- Sort by raw UTC timestamp.
- `healthAlerts` stores all unresolved alerts in the recent window for the summary card.
- `dashboardRecentAlerts` stores only the latest 3 for the Recent Health Alerts panel.

This avoids stale `alerts_latest` data.

### 11.6 Dashboard Rendering

Render functions:

```js
renderDashboard()
renderSummaryCards()
renderCatIntakeTable()
renderLatestRecordsTable()
renderRecentAlerts()
```

Summary card logic:

- Today's Feedings = `feedingRecords.length`
- Total Intake Today = sum of `cats.todayIntakeGrams`
- Active Alerts = unresolved alert count from recent alert window
- Device Status = `deviceStatus.feederOnline`

## 12. Feeding Records Page

Files:

- `records.html`
- `static/js/records.js`

Sections:

- Total Records
- Total Intake
- Average Intake
- Filters
- Feeding History

### 12.1 Data Loading

Constant:

```js
const RECORD_HISTORY_START_DATE = "2026-01-01";
```

Flow:

1. `loadBackendData()`
2. `loadAllFeedingRecords()`
3. `initialiseRecordsPage()`

`loadAllFeedingRecords()` calls:

```txt
GET /api/analytics/range?startDate=2026-01-01&endDate={PerthToday}
```

This loads the full feeding history window into `feedingRecords`.

### 12.2 Filters

Filter controls:

- Cat select
- Start Date
- End Date
- Reset Filters

Default state:

- Cat: `All Cats`
- Start Date: empty
- End Date: empty

Empty date fields mean all time within loaded history.

Filter logic:

```js
getFilteredRecords()
```

Applies:

- cat filter, if selected cat is not `all`
- start date, if not empty
- end date, if not empty

### 12.3 Summary Cards

Important behavior:

Summary cards use all loaded `feedingRecords`, not filtered records.

```js
updateSummaryCards(feedingRecords)
```

This means:

- Total Records = all loaded records
- Total Intake = all loaded intake
- Average Intake = all loaded average

The filter only affects the table.

## 13. Analytics Page

Files:

- `analytics.html`
- `static/js/analytics.js`

Sections:

- Highest Intake Cat
- Lowest Intake Cat
- Average Intake
- Range controls
- Per-cat summary cards
- Per-cat trend charts

Uses Chart.js.

### 13.1 Range Controls

Default preset:

```txt
today
```

Presets:

- today
- week
- month
- custom

For non-custom presets, start/end date inputs are auto-filled and disabled.

For custom preset, start/end date inputs are enabled.

### 13.2 Data Loading

```js
loadAnalyticsRangeFromControls()
```

Flow:

1. Read start and end date.
2. Validate `startDate <= endDate`.
3. Show loading state.
4. Fetch `/api/analytics/range`.
5. On failure, build fallback analytics from currently loaded data.
6. Render summary and charts.

### 13.3 Single-Day Chart

If `startDate === endDate`:

- One scatter chart per cat.
- X-axis is full 0-24h day.
- Each feeding is one point.
- X value is minutes since midnight Perth time.
- Y value is intake grams.

### 13.4 Multi-Day Chart

If `startDate !== endDate`:

- One line/area chart per cat.
- X-axis is date.
- Y-axis is daily intake grams.
- Uses `dailySeries` from analytics API.

### 13.5 Chart Lifecycle

Before rendering new cat charts:

- Existing charts whose keys start with `catTrend_` are destroyed.
- This prevents duplicate Chart.js instances and canvas reuse errors.

## 14. Health Alerts Page

Files:

- `alerts.html`
- `static/js/alerts.js`

Sections:

- Total Alerts
- Unresolved
- High Level
- Resolved
- Email Notifications
- Filters
- Alert Details
- Alert History

### 14.1 Alert History Loading

Constant:

```js
const ALERT_HISTORY_DAYS = 30;
```

Flow:

1. `loadBackendData()`
2. `loadAlertHistoryData()`
3. `renderAlertsPage()`
4. `renderAlertSubscriptionStatus()`

`loadAlertHistoryData()`:

- Computes `endDate = getPerthToday()`
- Computes `startDate = endDate - 29 days`
- Calls `/api/alerts/history`
- Transforms result into `healthAlerts`

If history loading fails:

- Uses whatever latest alert snapshot was loaded by `loadBackendData()`.

### 14.2 Alert Details vs Alert History

Current alert details:

```js
getCurrentAlerts()
```

Contains:

- only `Unresolved` alerts
- filtered by level if selected

Alert history:

```js
getFilteredHistoryAlerts()
```

Contains:

- all loaded alerts
- optionally filtered by status
- optionally filtered by level

Therefore:

- Alert Details shows current unresolved alerts.
- Alert History includes both current and resolved historical alerts.

### 14.3 Alert Filters

Controls:

- Status:
  - all
  - Unresolved
  - Resolved
- Level:
  - all
  - High
  - Medium
  - Low

Reset restores both filters to `all`.

### 14.4 Resolve Alert

Each unresolved alert gets:

```txt
Mark as Resolved
```

Click flow:

1. Find alert in `healthAlerts`.
2. Disable button and show resolving state.
3. Call `resolveBackendAlert(alert.id, alert.alertDate)`.
4. Update local alert status to `Resolved`.
5. Re-render page.

### 14.5 Email Subscription

Email form supports:

- subscribe
- unsubscribe
- status check

Behavior:

- On page load, calls `fetchAlertSubscriptions()`.
- On email input, debounced 400ms status check.
- Submit calls `toggleAlertEmailSubscription(email)`.
- Button text changes between Subscribe and Unsubscribe.
- Threshold is fixed in UI as `Medium and High`.

## 15. Cat Management Page

Files:

- `cats.html`
- `static/js/cats.js`

Sections:

- Total Cats
- RFID Tags
- Assigned Bowls
- Average Target
- Cat list/table
- Add/Edit form
- RFID status

### 15.1 Initial Loading

Flow:

1. `loadBackendData()`
2. `renderCatsPage()`
3. `resetCatForm()`

### 15.2 Rendering

Render functions:

```js
renderCatsPage()
renderCatSummary()
renderCatsTable()
updateCapacityState()
```

The prototype supports max 2 cats.

### 15.3 Add Cat

Adding a cat is local-only.

New local cats get:

```txt
backendCatId = local_cat_{id}
todayStatus = local
```

Validation:

- name required
- RFID required
- assigned bowl required
- daily target required
- max 2 cats
- bowl cannot be reused
- RFID cannot be reused

Local-added cats are not persisted to backend.

### 15.4 Edit Cat

If editing a backend cat:

```js
cat.backendCatId && !cat.backendCatId.startsWith("local_cat_")
```

Flow:

1. Validate form.
2. Call `updateCatProfile(cat.backendCatId, { catName, targetDailyGrams })`.
3. Reload backend data.
4. Re-render.

Backend profile changes then appear across:

- Dashboard
- Feeding Records
- Analytics
- Health Alerts
- Cat Management

because transformers prefer current cat profile names when matching `catId`.

If editing a local-only cat:

- Only updates the local `cats` array.

### 15.5 Delete Cat

Delete is local-only.

It removes the cat from the frontend `cats` array after confirmation.

It does not delete backend cat profiles.

### 15.6 RFID Rebind

For backend cats only.

Flow:

1. User clicks `Rebind RFID`.
2. Confirm prompt appears.
3. Frontend creates `activeRfidRebind`.
4. Calls `startRfidRebindScan(backendCatId, 120)`.
5. Backend sends C2D command to ESP32.
6. Frontend polls every 3 seconds.
7. Each poll calls `loadBackendData()`.
8. If cat RFID changes from old UID to new UID, scan is considered successful.
9. If timeout expires, active scan is cleared.

Polling interval:

```js
setInterval(..., 3000)
```

During active rebind:

- edit/delete/rebind buttons are disabled
- save/generate RFID controls are disabled

### 15.7 Local RFID Simulation

```js
simulateRfidScan()
```

Generates a random 8-character RFID tag and fills the form input.

This is local UI simulation only and does not communicate with backend.

## 16. Navigation and Shared Layout

Each HTML page has the same navbar:

- Dashboard
- Feeding Records
- Analytics
- Health Alerts
- Cat Management

Each page has:

- `page-heading-row`
- title and subtitle
- `device-sync-pill`
- footer with sync status

The active nav item is hard-coded per page.

## 17. Styling Architecture

All project-specific styles are in:

```txt
static/css/style.css
```

The frontend uses Bootstrap layout primitives:

- navbar
- container
- row/col grid
- cards
- tables
- forms
- buttons
- badges

Custom CSS handles:

- page title
- summary cards
- summary icons
- device sync pill
- sync dot
- alert callouts
- alert badges
- status badges
- intake progress bars
- analytics cat cards
- chart layout

## 18. Cache Busting

The project uses query string versions in script URLs:

```txt
?v=20260518-dashboard-recent-alerts
?v=20260518-records-range
?v=20260518-alert-current-history
?v=20260518-cat-profile-sync
```

The local `.bat` also opens:

```txt
index.html?v=20260518-local-refresh
```

Backend API calls include:

```txt
_={Date.now()}
```

Azure Storage uploads have been deployed with:

```txt
Cache-Control: no-store, no-cache, must-revalidate, max-age=0
```

## 19. Fallback Behavior

If backend loading fails:

```js
loadFallbackData()
```

sets:

- two sample cats
- sample feeding records
- sample health alert
- offline device status

This keeps the UI renderable even when backend is unavailable.

Pages may also have page-specific fallbacks:

- Analytics builds fallback analytics from currently loaded `cats` and `feedingRecords`.
- Alerts page falls back to the latest alert snapshot if history endpoint fails.
- Dashboard can preserve previous state during polling failures.

## 20. Deployment

Frontend files are static assets.

Azure Static Website storage account:

```txt
multicatproject
```

Static website URL:

```txt
https://multicatproject.z8.web.core.windows.net/
```

Typical upload command pattern:

```powershell
$account='multicatproject'
$root=Resolve-Path '5506-iot-smart-cat-feeder-frontend'
$files=@(
  'alerts.html',
  'analytics.html',
  'cats.html',
  'index.html',
  'records.html',
  'static/css/style.css',
  'static/js/alerts.js',
  'static/js/analytics.js',
  'static/js/api.js',
  'static/js/cats.js',
  'static/js/dashboard.js',
  'static/js/mockData.js',
  'static/js/records.js'
)

foreach ($file in $files) {
  az storage blob upload `
    --account-name $account `
    --auth-mode key `
    --container-name '$web' `
    --file (Join-Path $root $file) `
    --name $file `
    --overwrite true `
    --content-cache-control 'no-store, no-cache, must-revalidate, max-age=0' `
    --output none
}
```

Avoid broad `upload-batch` unless the source directory is clean, because it may upload unintended files.

## 21. Current Design Decisions

- Static frontend is simple to deploy and easy to run locally.
- Shared `api.js` avoids duplicated API wrappers.
- Global variables are acceptable for this small multi-page prototype.
- Backend is the source of truth for cat profiles, RFID, feeding data and alerts.
- Frontend-added cats are local-only.
- Dashboard uses polling rather than WebSocket/SSE.
- Dashboard recent alerts use alert history, not `alerts_latest`.
- Feeding Records summary cards intentionally ignore filters.
- Feeding Records table filters are client-side over loaded history.
- Cat name updates are propagated by backend profile update and frontend transform matching.

## 22. Known Limitations

- Function key is stored in frontend JavaScript, which is acceptable for this prototype but not ideal for production.
- No frontend router; each page is a separate HTML file.
- No bundler or module system; scripts rely on global scope and load order.
- No persistent client-side store.
- Local-added cats are not saved to backend.
- Delete cat is local-only.
- Feeding Records loads history from `2026-01-01`; older records would require changing `RECORD_HISTORY_START_DATE`.
- Dashboard polling is HTTP polling, not true push.
- Alert History currently loads the most recent 30 days.
- Dashboard Recent Alerts currently displays latest 3 unresolved alerts from the latest 7-day window.

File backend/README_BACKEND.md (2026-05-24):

# Smart Multi-Cat Feeder Azure Backend

Backend-only Azure Functions implementation for IoT Hub feeding messages.

## Deployed Azure Resources

- Resource group: `IOT-Group17`
- IoT Hub: `multicatfeeder`
- IoT Hub device: `feeder-esp32-01`
- Existing data storage account: `multicatproject`
- Existing raw container: `raw-iot-data`
- Deployed Function App: `multicatfeeder-func-24417624`
- Function runtime storage account: `mcfbackend24417624`

The Function runtime storage account is separate from the existing project data storage. Backend tables, raw data, and backend JSON outputs remain in `multicatproject`.

## What Is Implemented

- IoT Hub/Event Hub-triggered processing for `feeding_complete`
- Direct JSON and IoT Hub wrapper `Body` base64 parsing
- Azure Table Storage models:
  - `CatProfiles`
  - `RfidMap`
  - `RfidHistory`
  - `FeedingEvents`
  - `DailySummary`
  - `CurrentStatus`
  - `Alerts`
- Blob outputs:
  - `backend-data/current-status.json`
  - `backend-data/daily-summary/YYYY-MM-DD.json`
  - `backend-data/recent-feedings/YYYY-MM-DD.json`
  - `backend-data/alerts/latest.json`
- Backfill tool for existing raw blobs
- RFID update script and protected admin API
- Device Twin desired-property sync
- Backend testing APIs only; no frontend UI

Note: the runtime entry module is `backend_app.py`. The project uses classic `function.json` folders for Azure Functions indexing because a root `function_app.py` file causes Azure's Python v2 worker indexing path to take over.

## Local Setup

```powershell
python -m pip install -r requirements.txt
python -m pip install -r requirements-dev.txt
Copy-Item local.settings.template.json local.settings.json
```

Fill `local.settings.json` with real Azure values. Do not commit it.

Required settings:

- `AzureWebJobsStorage`
- `STORAGE_CONNECTION_STRING`
- `IOT_HUB_EVENTHUB_CONNECTION`
- `IOT_HUB_EVENTHUB_NAME`
- `IOT_HUB_CONNECTION_STRING`
- `IOT_HUB_NAME`
- `IOT_HUB_DEVICE_ID`
- `RAW_CONTAINER`
- `LOCAL_TIMEZONE`

## Azure Inspection

Run these in a shell where Azure CLI is available:

```powershell
az account show
az group list -o table
az iot hub list -o table
az storage account list -o table
az functionapp list -o table
az storage container list --account-name <storage-account-name> -o table
```

## Seed Initial Data

```powershell
$env:AzureWebJobsStorage="<storage connection string>"
$env:STORAGE_CONNECTION_STRING="<storage connection string>"
$env:IOT_HUB_CONNECTION_STRING="<IoT Hub service connection string>"
$env:IOT_HUB_NAME="<hub name>"
$env:IOT_HUB_DEVICE_ID="feeder-esp32-01"
$env:RAW_CONTAINER="<raw container>"
python tools/seed_cat_profiles.py
```

## Run Sample Backend Test Script

```powershell
python tools/test_with_sample_events.py
```

## Backfill Existing Raw Blobs

```powershell
python tools/reprocess_raw_blobs.py
```

The tool is idempotent. It uses:

```text
{deviceId}-{catId}-{feedingEndTime}
```

as the feeding event key.

## RFID Update

```powershell
python tools/update_cat_rfid.py --cat-id cat_a --new-cat-uid A1B2C3D4 --effective-time-utc 2026-05-20T10:00:00Z
```

This preserves old RFID history, updates `CatProfiles.currentCatUID`, increments `configVersion`, and pushes Device Twin desired properties when `IOT_HUB_CONNECTION_STRING` is configured.

## Deploy

After Azure CLI and Azure Functions Core Tools are available:

```powershell
func azure functionapp publish <function-app-name>
```

Then configure Function App settings with the values from `local.settings.template.json`.

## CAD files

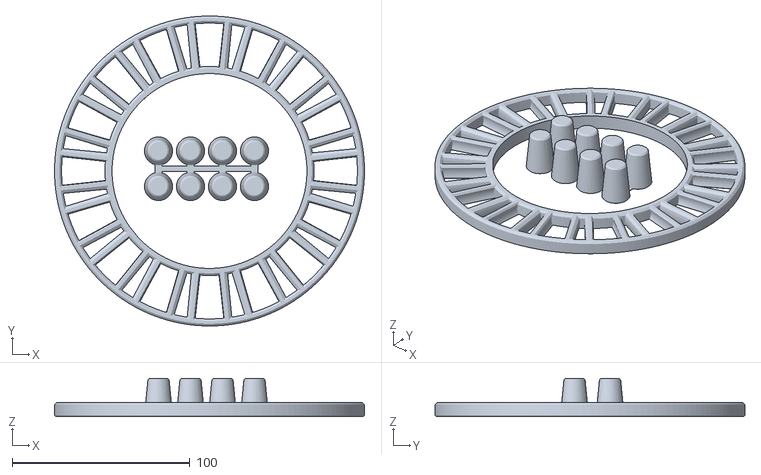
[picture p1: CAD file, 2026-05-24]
hardware/3d/200/carrier_pin200.stl
174.4 x 174.4 x 21.6

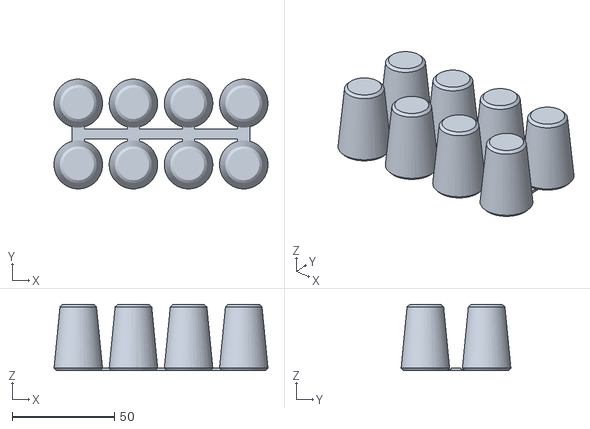
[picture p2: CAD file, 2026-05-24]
hardware/3d/300/pins300.stl
104.7 x 53.8 x 32.4

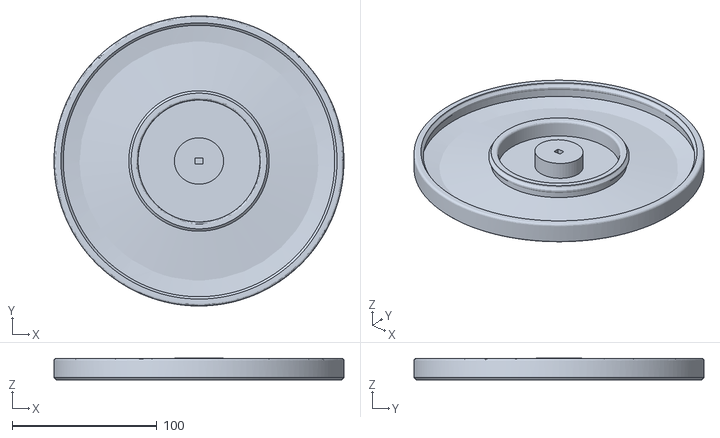
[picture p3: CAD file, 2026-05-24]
hardware/3d/200/top200.stl
200.0 x 200.0 x 15.0

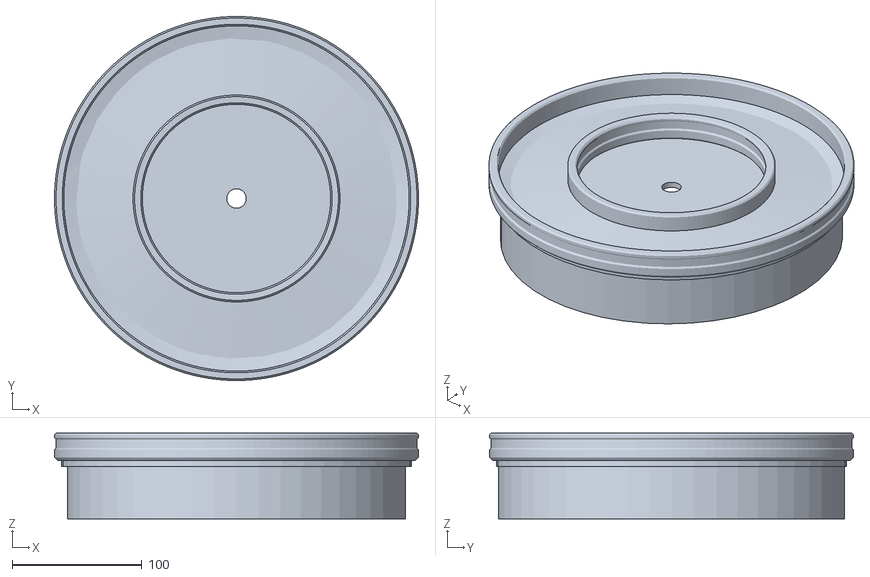
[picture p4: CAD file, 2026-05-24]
hardware/3d/300/bottom300.stl
280.8 x 280.8 x 66.0

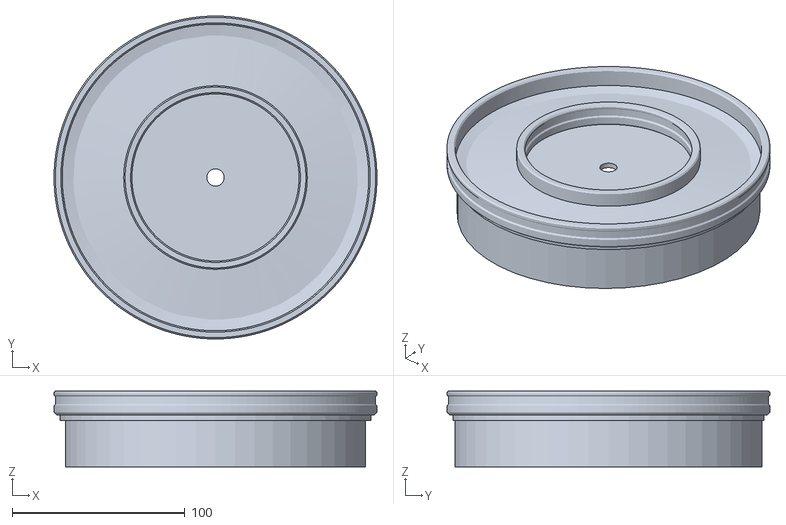
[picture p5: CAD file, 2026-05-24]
hardware/3d/200/bottom200.stl
187.2 x 187.2 x 44.0

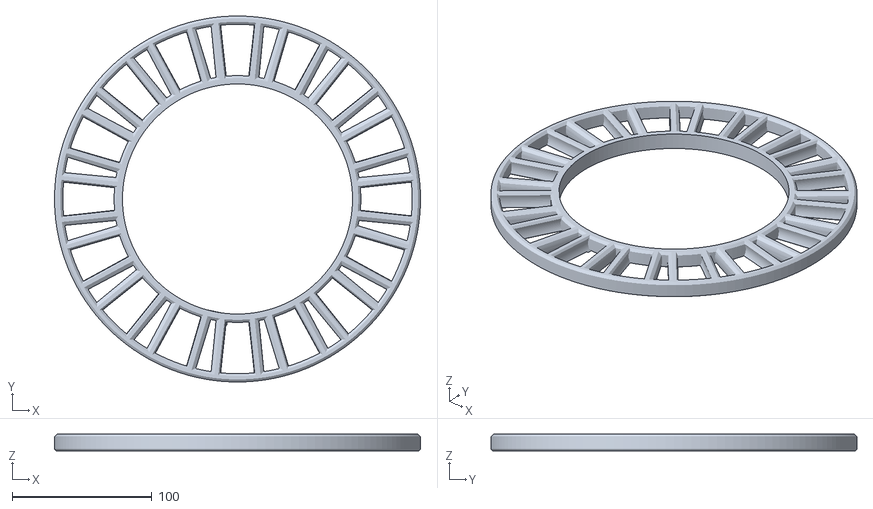
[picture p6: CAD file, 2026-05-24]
hardware/3d/300/carrier300.stl
261.6 x 261.6 x 12.0

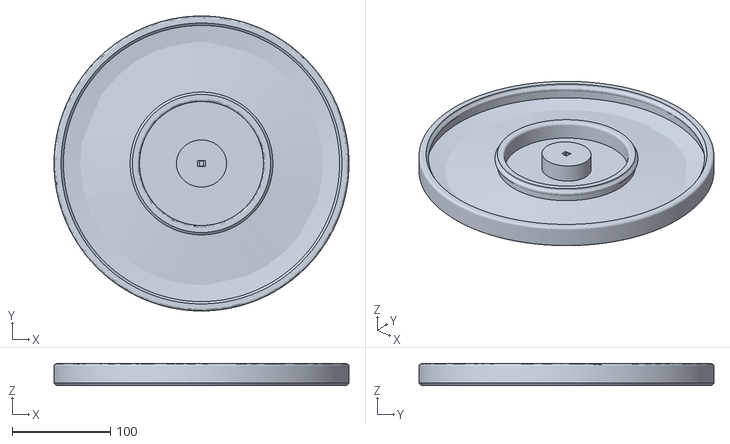
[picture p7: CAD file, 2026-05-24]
hardware/3d/300/top300.stl
300.0 x 300.0 x 22.5

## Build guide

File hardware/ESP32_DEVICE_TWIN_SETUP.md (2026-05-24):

# ESP32 Azure IoT Hub Device Twin Setup

This document is for the ESP32 firmware developer. It explains how the ESP32 should connect to Azure IoT Hub, read Device Twin configuration, apply RFID changes, and report configuration sync status.

## Device Connection

IoT Hub host:

```text
multicatfeeder.azure-devices.net
```

IoT Hub name:

```text
multicatfeeder
```

Device ID:

```text
feeder-esp32-01
```

Device connection string:

```text
HostName=<iot-hub-host>;DeviceId=feeder-esp32-01;SharedAccessKey=<device-primary-key>
```

Use the device connection string only on the ESP32/device side. Do not use backend service connection strings, Azure Storage connection strings, Function App keys, or Azure CLI user credentials in firmware.

## Required Device Twin Behavior

The ESP32 must not hard-code cat RFID UIDs in firmware.

On startup, the ESP32 should:

1. Connect to Azure IoT Hub using the device connection string.
2. Read Device Twin `properties.desired`.
3. Build a local RFID mapping from `cats`.
4. Store the applied `configVersion`.
5. Report the applied configuration through Device Twin `properties.reported`.

While running, the ESP32 should:

1. Listen for desired property patch updates.
2. Check whether the received `configVersion` is newer than the currently applied version.
3. If newer, refresh the local RFID mapping.
4. Report the new applied version after the update succeeds.

## Current Desired Twin Configuration

The ESP32 should read this structure from Device Twin `properties.desired`:

```json
{
  "configVersion": 1,
  "cats": {
    "cat_a": {
      "catName": "CatA",
      "catUID": "B9BD18C9",
      "minimumMeaningfulIntakeGrams": 2.0,
      "targetDailyGrams": 60.0
    },
    "cat_b": {
      "catName": "CatB",
      "catUID": "0420D6BAFD1691",
      "minimumMeaningfulIntakeGrams": 2.0,
      "targetDailyGrams": 60.0
    }
  },
  "feedingRules": {
    "allowUnknownRfid": false,
    "minFeedingIntervalHours": 8
  }
}
```

Fields the ESP32 must support:

```text
configVersion
cats.<catId>.catName
cats.<catId>.catUID
cats.<catId>.targetDailyGrams
cats.<catId>.minimumMeaningfulIntakeGrams
feedingRules.allowUnknownRfid
feedingRules.minFeedingIntervalHours
```

The current cat IDs are:

```text
cat_a
cat_b
```

RFID UID values should be treated as exact string IDs. Recommended firmware handling:

```text
uppercase
no spaces
no separators unless the RFID reader library requires them internally
```

## Reported Twin Properties

After applying desired configuration, the ESP32 should update Device Twin `properties.reported`.

Use this format:

```json
{
  "configVersionApplied": 1,
  "knownCats": {
    "cat_a": "B9BD18C9",
    "cat_b": "0420D6BAFD1691"
  },
  "lastSyncTime": "2026-05-16T08:00:00Z"
}
```

Required reported fields:

```text
configVersionApplied
knownCats
lastSyncTime
```

`lastSyncTime` should be UTC ISO 8601 time.

The backend uses `configVersionApplied` to check whether the ESP32 has applied the latest RFID configuration. If this field is missing or old, the backend may report the device config as out of sync.

## RFID Change Flow

RFID changes are made from the backend/admin side, not by changing ESP32 firmware.

For the current implementation, the frontend user must choose both:

```text
action: rebind RFID
target cat: cat_a or cat_b
```

The backend does not need to infer which cat should be updated in this flow.

This is not an `add_cat` or `remove_cat` flow. It is a rebind flow for one existing cat:

```text
same cat
same bowl
same catName
old RFID UID replaced by new RFID UID
```

One-off scan commands should be sent to the ESP32 as Cloud-to-Device messages. Device Twin desired properties should remain the source of truth for the final persistent cat RFID configuration.

### Start RFID Rebind Scan Command

When the user clicks `Rebind RFID` for a selected cat, the backend records the selected cat in the pending operation and sends this simple C2D command to the ESP32:

```json
{
  "action": "start_scan",
  "operationId": "rfid-op-20260516-001",
  "trayIndex": 0,
  "timeoutSec": 120
}
```

Required command fields:

```text
action must be start_scan
operationId uniquely identifies this scan operation
trayIndex identifies which tray/bowl belongs to the selected cat
timeoutSec is the scan timeout in seconds
```

Current tray mapping:

```text
cat_a -> trayIndex 0
cat_b -> trayIndex 1
```

ESP32 behavior after receiving this command:

1. Enter a dedicated RFID scan mode.
2. Use a 2-minute timeout unless `timeoutSec` says otherwise.
3. Use `trayIndex` if the scan flow requires moving or indicating the selected tray.
4. Do not treat the scanned tag as a feeding attempt.
5. Read the next RFID UID, even if it is not in the local whitelist.
6. Send a `tag_scanned` telemetry message to the backend.
7. Exit scan mode after a successful scan, timeout, or cancel command.

This scan mode is separate from the normal feeding state. In the current hardware logic, unknown RFID tags do not enter `FEEDING`, so the ESP32 must send a separate scan event when it reads a new tag during rebind mode.

The backend already knows which cat the user selected. The ESP32 does not need to decide whether the new UID belongs to `cat_a` or `cat_b`. `trayIndex` is provided so the ESP32 knows which tray/bowl is associated with the selected cat.

### Tag Scanned Telemetry

After the ESP32 scans the new RFID tag, it should send this telemetry:

```json
{
  "deviceId": "feeder-esp32-01",
  "event": "tag_scanned",
  "operationId": "rfid-op-20260516-001",
  "uid": "NEW_UID_HERE",
  "timestamp": 1778918400
}
```

Required scan telemetry fields:

```text
event must be tag_scanned
operationId must match the start_scan command
uid is the newly scanned RFID UID
timestamp is a Unix timestamp in seconds
```

Recommended UID formatting:

```text
uppercase
no spaces
no separators
```

Example:

```json
{
  "deviceId": "feeder-esp32-01",
  "event": "tag_scanned",
  "operationId": "rfid-op-20260516-001",
  "uid": "04A1B2C3D4",
  "timestamp": 1778918400
}
```

### RFID Scan Status

The ESP32 may also send status telemetry during the scan flow:

```json
{
  "deviceId": "feeder-esp32-01",
  "event": "scan_status",
  "operationId": "rfid-op-20260516-001",
  "status": "armed",
  "timestamp": 1778918380
}
```

Allowed status values:

```text
armed
scanned
timeout
cancelled
failed
```

If the scan times out:

```json
{
  "deviceId": "feeder-esp32-01",
  "event": "scan_status",
  "operationId": "rfid-op-20260516-001",
  "status": "timeout",
  "reason": "no_tag_detected",
  "timestamp": 1778918700
}
```

### Cancel RFID Scan Command

If the user cancels the operation, the backend sends:

```json
{
  "action": "cancel_scan",
  "operationId": "rfid-op-20260516-001"
}
```

ESP32 should exit RFID scan mode and return to normal idle/feeding detection.

### Backend Update After Scan

After receiving valid `tag_scanned` telemetry, the backend will:

1. Verify that `operationId` is still active.
2. Look up the selected cat from the pending operation created by the frontend.
3. Check that the new `uid` is not already assigned to another cat.
4. Update the selected cat's RFID mapping.
5. Preserve old RFID history.
6. Increment `configVersion`.
7. Push updated persistent configuration through Device Twin desired properties.

The ESP32 should then receive the Device Twin desired change, update its local whitelist, save it to NVS, and report the applied version through reported properties.

When a cat RFID changes, the backend will:

1. Update the cat profile.
2. Preserve old RFID history.
3. Increment `configVersion`.
4. Push new Device Twin desired properties.

The ESP32 should then receive the desired property update, apply the new `catUID`, and report the new `configVersionApplied`.

Example desired twin after changing `cat_a` RFID:

```json
{
  "configVersion": 2,
  "cats": {
    "cat_a": {
      "catName": "CatA",
      "catUID": "NEW_UID_HERE",
      "minimumMeaningfulIntakeGrams": 2.0,
      "targetDailyGrams": 60.0
    },
    "cat_b": {
      "catName": "CatB",
      "catUID": "0420D6BAFD1691",
      "minimumMeaningfulIntakeGrams": 2.0,
      "targetDailyGrams": 60.0
    }
  },
  "feedingRules": {
    "allowUnknownRfid": false,
    "minFeedingIntervalHours": 8
  }
}
```

Expected reported twin after applying it:

```json
{
  "configVersionApplied": 2,
  "knownCats": {
    "cat_a": "NEW_UID_HERE",
    "cat_b": "0420D6BAFD1691"
  },
  "lastSyncTime": "2026-05-16T08:05:00Z"
}
```

## Feeding Complete Telemetry

After recognizing a cat and completing a feeding measurement, the ESP32 should send telemetry to IoT Hub using this JSON format:

```json
{
  "deviceId": "feeder-esp32-01",
  "catName": "CatA",
  "catUID": "B9BD18C9",
  "event": "feeding_complete",
  "feedingStartTime": 1778918400,
  "feedingEndTime": 1778918700,
  "durationSec": 300,
  "intakeGrams": 12.5
}
```

Telemetry requirements:

```text
event must be feeding_complete
feedingStartTime is a Unix timestamp in seconds
feedingEndTime is a Unix timestamp in seconds
durationSec should equal feedingEndTime - feedingStartTime
intakeGrams should be numeric and must not be negative when the scale is working
intakeGrams may be null only when the weight/scale sensor failed
catUID must match one of the Device Twin desired catUID values
deviceId should be feeder-esp32-01
```

If the weight/scale sensor fails during a feeding attempt, send `intakeGrams` as JSON `null`:

```json
{
  "deviceId": "feeder-esp32-01",
  "catName": "CatB",
  "catUID": "0420D6BAFD1691",
  "event": "feeding_complete",
  "feedingStartTime": 1778918400,
  "feedingEndTime": 1778918700,
  "durationSec": 300,
  "intakeGrams": null
}
```

The backend treats `intakeGrams: null` as a scale sensor failure. It will create a `scale_sensor_error` alert and will not count the event toward the cat's daily intake total.

## Heartbeat Telemetry

The ESP32 may send heartbeat telemetry with hardware health checks:

```json
{
  "deviceId": "feeder-esp32-01",
  "event": "heartbeat",
  "timestamp": 1778918400,
  "rfid_ok": true,
  "tof_ok": true,
  "motor_ok": true
}
```

Heartbeat fields:

```text
timestamp is a Unix timestamp in seconds
rfid_ok reports RFID reader health
tof_ok reports time-of-flight sensor health
motor_ok reports motor health
```

If any health check is `false`, the backend treats it as a device health issue and creates a `device_health_error` alert.

## Handling Unknown RFID

Current cloud setting:

```text
feedingRules.allowUnknownRfid = false
```

Recommended ESP32 behavior:

1. If scanned RFID matches a configured `catUID`, proceed with normal feeding logic.
2. If scanned RFID is unknown and `allowUnknownRfid` is `false`, do not treat it as a known cat.
3. Optionally send diagnostic telemetry/logging for unknown RFID, but do not send a normal `feeding_complete` event as if it belonged to CatA or CatB.

## Acceptance Checklist

The integration is working when:

```text
ESP32 connects to IoT Hub as feeder-esp32-01
ESP32 reads Device Twin desired properties
ESP32 applies cat_a and cat_b RFID UIDs from desired twin
ESP32 reports configVersionApplied
ESP32 reports knownCats
ESP32 updates reported properties again after desired configVersion changes
ESP32 sends feeding_complete telemetry with the configured catUID
```

## Security Notes

The device connection string contains the ESP32 device key.

Do not share real keys publicly.
Do not commit real keys to a public repository.
Do not put backend/admin connection strings into ESP32 firmware.
If the key is leaked, regenerate the device key in Azure IoT Hub and update the ESP32 firmware/config.

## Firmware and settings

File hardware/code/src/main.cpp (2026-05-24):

#include <Arduino.h>
#include <Wire.h>
#include "config.h"
#include "rfid_module.h"
#include "motor_module.h"
#include "distance_module.h"
#include "loadcell_module.h"
#include "azure_iot_module.h"

// FSM state definition
enum State { IDLE, DETECTING, OPENING, FEEDING, CLOSING, SCAN_RFID };
static State state = IDLE;

// Runtime state variables (currentCatIndex is non-static to allow extern access from azure_iot_module)
int currentCatIndex = -1;
static unsigned long stateEnterTime = 0;
static unsigned long catAbsentStart = 0;   // Cat absence continuous timer start
static unsigned long feedingStartTime = 0; // Feeding start time for telemetry upload
static float initialWeight = 0;  // Food weight when bowl opens (-1 = weighing unavailable)
static float finalWeight = 0;    // Food weight when bowl closes
static float intakeGrams = 0;    // Food intake this cycle (-1 = no data)

// Hardware health status (used in heartbeat)
static bool motorOk = true;

// Scan mode global variables
String currentOperationId = "";
unsigned long scanTimeoutMs = 120000;

// External interface to enter scan mode (called by azure_iot_module)
void startScanMode(const String& opId, int timeoutSec, int trayIndex) {
  if (state != IDLE && state != SCAN_RFID) {
    Serial.println(F("[SCAN] Device is currently feeding, cannot enter scan mode"));
    // Wrong state, send failed status
    azure_sendScanStatus(opId, "failed", "device_busy");
    return;
  }
  currentOperationId = opId;
  scanTimeoutMs = timeoutSec * 1000UL;
  state = SCAN_RFID;
  stateEnterTime = millis();
  
  Serial.printf("[SCAN] Entering RFID scan mode, OperationID: %s, Timeout: %ds, Target Tray: %d\n", 
                opId.c_str(), timeoutSec, trayIndex);
                
  if (trayIndex >= 0) {
    Serial.printf("[SCAN] Tip: Motor could rotate to indicate tray %d if needed\n", trayIndex);
  }

  azure_sendScanStatus(opId, "armed");
}

void cancelScanMode() {
  if (state == SCAN_RFID) {
    Serial.println(F("[SCAN] Scan cancelled by user, returning to IDLE"));
    azure_sendScanStatus(currentOperationId, "cancelled");
    currentOperationId = "";
    state = IDLE;
  }
}

void printState(const char* stateName) {
  Serial.print(F("==== STATE: "));
  Serial.print(stateName);
  Serial.println(F(" ===="));
}

void setup() {
  Serial.begin(115200);
  delay(1000);

  // 1. Initialize I2C bus
  Wire.begin(I2C_SDA, I2C_SCL);

  // 2. Initialize all sub-modules (any module failure will not freeze the system)
  rfid_init();
  motor_init();
  distance_init();
  loadcell_init();

  // 3. Initialize Azure IoT Hub connection (WiFi + NTP + MQTT)
  azure_init();

  // Print system status
  Serial.println(F("\n--- Smart Cat Feeder V6.0 Online ---"));
  Serial.printf("[System] RFID: %s | Distance Sensor: %s\n",
                rfid_isAvailable() ? "OK" : "FAIL",
                distance_isAvailable() ? "OK" : "FAIL");
  Serial.printf("[System] Whitelisted Cats: %d\n", rfid_getCatCount());

  // 4. Report hardware faults (only after Azure connection is established)
  if (!rfid_isAvailable()) {
    azure_sendHardwareFault("RFID", "init_failed");
  }
  if (!distance_isAvailable()) {
    azure_sendHardwareFault("ToF", "init_failed");
  }

  // 5. Send boot heartbeat
  azure_sendHeartbeat(rfid_isAvailable(), distance_isAvailable(), motorOk);

  printState("IDLE");
}

void loop() {
  // === Serial command handler (for testing without physical RFID tags) ===
  if (Serial.available()) {
    String cmd = Serial.readStringUntil('\n');
    cmd.trim();
    if (cmd == "REBOOT") {
      Serial.println(F("Received reboot command, restarting..."));
      delay(500);
      ESP.restart();
    } else if (cmd.startsWith("SIMULATE:")) {
      String mockUid = cmd.substring(9);
      mockUid.trim();
      extern void rfid_injectMock(const String&);
      rfid_injectMock(mockUid);
      Serial.printf("[MOCK] Injected virtual tag UID: %s\n", mockUid.c_str());
    }
  }

  // Core: advance stepper motor by one step (if target is set). Non-blocking, executes very fast.
  motor_update();

  // Maintain Azure MQTT connection (auto-reconnect + token refresh + resend cached data)
  azure_loop();

  // Send heartbeat periodically (every 5 minutes)
  static unsigned long lastHeartbeat = 0;
  if (millis() - lastHeartbeat > 300000) {
    azure_sendHeartbeat(rfid_isAvailable(), distance_isAvailable(), motorOk);
    lastHeartbeat = millis();
  }

  switch (state) {
    case IDLE: {
      // Standby: only distance sensor is active as a "gatekeeper"
      if (distance_isCatPresent()) {
        Serial.println(F("[IDLE] Object detected in tunnel, waking up RFID..."));
        state = DETECTING;
        stateEnterTime = millis();
        printState("DETECTING");
      }
      break;
    }

    case DETECTING: {
      // 1. Check timeout
      if (millis() - stateEnterTime > RFID_DETECT_TIMEOUT_MS) {
        Serial.println(F("[DETECTING] RFID timeout (no collar?). Returning to IDLE"));
        state = IDLE;
        printState("IDLE");
        break;
      }
      
      // 2. Check if cat left
      if (!distance_isCatPresent()) {
        Serial.println(F("[DETECTING] Cat left. Canceling scan, returning to IDLE"));
        state = IDLE;
        printState("IDLE");
        break;
      }

      // 3. Attempt to read RFID
      String uid;
      if (rfid_tryRead(uid)) {
        Serial.print(F("[DETECTING] Scanned tag: "));
        Serial.println(uid);

        int catIdx = rfid_verifyCat(uid);
        if (catIdx >= 0) {
          CatProfile* cat = rfid_getCatProfile(catIdx);
          Serial.printf(">> ID Confirmed: Welcome %s! Preparing food...\n", cat->name.c_str());
          
          currentCatIndex = catIdx;
          
          motor_moveTo(cat->bowlSteps);
          
          state = OPENING;
          stateEnterTime = millis();
          printState("OPENING");
        } else {
          Serial.println(F("WARNING: Unauthorized tag detected! Access denied."));
          delay(500);  // Prevent log spam
        }
      }
      break;
    }

    case OPENING: {
      // Wait for motor to reach the target bowl position
      if (motor_isAtTarget()) {
        motor_disableOutputs(); // Disable coils immediately to prevent overheating
        motorOk = true;         // Motor executed successfully, mark as healthy

        // Record initial food weight
        CatProfile* cat = rfid_getCatProfile(currentCatIndex);
        if (cat) {
          initialWeight = loadcell_readGrams(cat->bowlIndex);
          if (initialWeight > -9000.0f) {
            Serial.printf("[OPENING] Initial weight: %.1f g\n", initialWeight);
          } else {
            Serial.println(F("[OPENING] Load cell unavailable, skipping intake calculation"));
          }
        }

        Serial.println(F("[OPENING] Bowl opened, cat is eating..."));
        state = FEEDING;
        stateEnterTime = millis();
        feedingStartTime = millis();
        catAbsentStart = 0;
        printState("FEEDING");
        break;
      }

      // Motor timeout protection
      if (millis() - stateEnterTime > MOTOR_TIMEOUT_MS) {
        Serial.println(F("[OPENING] Motor timeout! Disabling outputs, returning to IDLE"));
        motor_disableOutputs();
        motorOk = false;  // Mark motor as faulty
        azure_sendHardwareFault("Motor", "opening_timeout");
        currentCatIndex = -1;
        state = IDLE;
        printState("IDLE");
      }
      break;
    }

    case FEEDING: {
      unsigned long now = millis();

      // Logic 1: Check if cat is still eating
      if (distance_isCatPresent()) {
        catAbsentStart = 0;  // Cat is still present, reset absence timer
      } else {
        // Cat is outside the distance sensor threshold
        if (catAbsentStart == 0) {
          catAbsentStart = now;  // Record when cat first disappeared
        } else if (now - catAbsentStart > CAT_LEAVE_TIMEOUT_MS) {
          // Cat has been absent for 3 consecutive seconds -> confirmed departure
          // Record closing weight and calculate intake
          CatProfile* cat = rfid_getCatProfile(currentCatIndex);
          if (cat && initialWeight > -9000.0f) {
            finalWeight = loadcell_readGrams(cat->bowlIndex);
            if (finalWeight > -9000.0f) {
              intakeGrams = initialWeight - finalWeight;
              if (intakeGrams < 0) intakeGrams = 0;
            } else {
              intakeGrams = -1;  // Weighing unavailable
            }
          } else {
            intakeGrams = -1;
          }

          if (cat) {
            if (intakeGrams >= 0) {
              Serial.printf("[FEEDING] Final weight: %.1f g, Intake: %.1f g\n", finalWeight, intakeGrams);
            }
            Serial.printf("[FEEDING] %s has left (for %d seconds), closing bowl...\n", 
                          cat->name.c_str(), CAT_LEAVE_TIMEOUT_MS/1000);
          }
          
          motor_returnHome();
          state = CLOSING;
          stateEnterTime = millis();
          printState("CLOSING");
          break;
        }
      }

      // Logic 2: Max feeding time enforcement (forced close)
      if (now - stateEnterTime > MAX_FEEDING_TIME_MS) {
        CatProfile* cat = rfid_getCatProfile(currentCatIndex);
        if (cat && initialWeight > -9000.0f) {
          finalWeight = loadcell_readGrams(cat->bowlIndex);
          if (finalWeight > -9000.0f) {
            intakeGrams = initialWeight - finalWeight;
            if (intakeGrams < 0) intakeGrams = 0;
          } else {
            intakeGrams = -1;
          }
        } else {
          intakeGrams = -1;
        }
        if (intakeGrams >= 0) {
          Serial.printf("[FEEDING] Timeout - Final weight: %.1f g, Intake: %.1f g\n", finalWeight, intakeGrams);
        }
        Serial.println(F("[FEEDING] Max feeding time reached, forcing close!"));
        motor_returnHome();
        state = CLOSING;
        stateEnterTime = millis();
        printState("CLOSING");
      }
      break;
    }

    case CLOSING: {
      // Wait for motor to return to home position (includes backlash compensation)
      if (motor_isAtTarget()) {
        motor_disableOutputs(); // Motor at home, disable coils
        motorOk = true;         // Motor executed successfully, mark as healthy

        // Send feeding record to Azure IoT Hub
        azure_sendFeedingData(currentCatIndex, feedingStartTime, intakeGrams);

        Serial.println(F("[CLOSING] --- Bowl closed securely, system IDLE ---\n"));
        currentCatIndex = -1;
        state = IDLE;
        printState("IDLE");
        break;
      }

      // Motor timeout protection
      if (millis() - stateEnterTime > MOTOR_TIMEOUT_MS) {
        Serial.println(F("[CLOSING] Motor timeout! Disabling outputs"));
        motor_disableOutputs();
        motorOk = false;  // Mark motor as faulty
        azure_sendHardwareFault("Motor", "closing_timeout");

        // Upload feeding data even if closing failed
        azure_sendFeedingData(currentCatIndex, feedingStartTime, intakeGrams);

        currentCatIndex = -1;
        state = IDLE;
        printState("IDLE");
      }
      break;
    }

    case SCAN_RFID: {
      // Scan timeout
      if (millis() - stateEnterTime > scanTimeoutMs) {
        Serial.println(F("[SCAN] Scan timed out, no new tag detected"));
        azure_sendScanStatus(currentOperationId, "timeout", "no_tag_detected");
        currentOperationId = "";
        state = IDLE;
        printState("IDLE");
        break;
      }

      // Try reading RFID
      String uid;
      if (rfid_tryRead(uid)) {
        Serial.printf("[SCAN] Tag scanned: %s\n", uid.c_str());
        // Send telemetry and status; cloud decides which cat to assign
        azure_sendScanTelemetry(currentOperationId, uid);
        azure_sendScanStatus(currentOperationId, "scanned");
        
        currentOperationId = "";
        state = IDLE;
        printState("IDLE");
      }
      break;
    }
  }

  // Small delay to reduce CPU and I2C bus utilization
  delay(10);
}

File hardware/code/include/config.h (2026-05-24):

#ifndef CONFIG_H
#define CONFIG_H

#include <Arduino.h>

// === I2C ===
#define I2C_SDA  21
#define I2C_SCL  22
#define RFID_I2C_ADDR  0x2C
#define TOF_I2C_ADDR   0x29

// === Stepper Motor (28BYJ-48) ===
#define MOTOR_IN1  25
#define MOTOR_IN2  26
#define MOTOR_IN3  14
#define MOTOR_IN4  13
#define STEPS_PER_REV       4096
#define MOTOR_MAX_SPEED     800.0
#define MOTOR_ACCELERATION  400.0
#define BACKLASH_STEPS      20    // Gear backlash compensation

// === Bowl Positions (in steps) ===
#define BOWL_LEFT_STEPS   (-1024)  // Cat A: counter-clockwise 90 deg
#define BOWL_RIGHT_STEPS  (1024)   // Cat B: clockwise 90 deg
#define HOME_POSITION     0        // Closed position

// === Distance Sensor ===
#define CAT_PRESENT_THRESHOLD_MM  50  // <50mm = cat is in the tunnel
#define CAT_LEAVE_TIMEOUT_MS      3000 // 3 seconds no object = cat left

// === RFID ===
#define RFID_DETECT_TIMEOUT_MS    5000 // DETECTING state max wait 5 seconds

// === Feeding ===
#define MAX_FEEDING_TIME_MS  300000  // 5 minutes forced close

// === Cat Profiles ===
#define MAX_CATS  2  // Max 2 cats (limited by 2 load cells)

// === Motor Timeout ===
#define MOTOR_TIMEOUT_MS  15000  // Motor pulses not finished in 15s = blocked

// === Load Cell (HX711) ===
#define LC1_DOUT_PIN  17    // Left bowl data
#define LC1_SCK_PIN   16    // Left bowl clock
#define LC2_DOUT_PIN  18    // Right bowl data
#define LC2_SCK_PIN   19    // Right bowl clock

// Calibration factors (calibrated with iPhone 16 Pro, 199g)
#define LOADCELL_1_CALIBRATION  232.27f  // Left bowl
#define LOADCELL_2_CALIBRATION  225.1f   // Right bowl

#endif

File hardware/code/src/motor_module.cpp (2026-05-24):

#include "motor_module.h"
#include "config.h"
#include <AccelStepper.h>

// 28BYJ-48 half-step mode (HALF4WIRE=8)
// Note: pin order is IN1, IN3, IN2, IN4 (AccelStepper requires crossed wiring)
static AccelStepper stepper(AccelStepper::HALF4WIRE, MOTOR_IN1, MOTOR_IN3, MOTOR_IN2, MOTOR_IN4);

// Flags for the homing/backlash compensation process
static bool isReturningHome = false;
static bool backlashPhase = false;

void motor_init() {
  stepper.setMaxSpeed(MOTOR_MAX_SPEED);
  stepper.setAcceleration(MOTOR_ACCELERATION);
  
  // Assume motor starts at closed position (0)
  stepper.setCurrentPosition(HOME_POSITION);
  
  Serial.println(F("[MOTOR] Stepper initialized."));
}

void motor_moveTo(int targetSteps) {
  stepper.enableOutputs();
  isReturningHome = false;
  backlashPhase = false;
  stepper.moveTo(targetSteps);
}

void motor_returnHome() {
  stepper.enableOutputs();
  isReturningHome = true;
  backlashPhase = false;
  
  // When closing: overshoot past home to compensate for gear backlash
  // Determine overshoot direction based on current position
  long currentPos = stepper.currentPosition();
  if (currentPos > 0) { // At right bowl (positive), must go negative to return
    stepper.moveTo(HOME_POSITION - BACKLASH_STEPS);
  } else if (currentPos < 0) { // At left bowl (negative), must go positive to return
    stepper.moveTo(HOME_POSITION + BACKLASH_STEPS);
  } else {
    // Already at home
    stepper.moveTo(HOME_POSITION);
  }
}

bool motor_update() {
  bool moving = stepper.run();
  
  // Handle the two-phase backlash compensation process
  if (isReturningHome && !moving) {
    if (!backlashPhase) {
      // Overshoot complete, now move to exact home position
      backlashPhase = true;
      stepper.moveTo(HOME_POSITION);
    } else {
      // Returned to exact home position, homing complete
      isReturningHome = false;
    }
  }
  
  // Combined motion status
  return moving || (isReturningHome && !moving);
}

bool motor_isAtTarget() {
  return stepper.distanceToGo() == 0 && !isReturningHome;
}

void motor_disableOutputs() {
  stepper.disableOutputs();
}
